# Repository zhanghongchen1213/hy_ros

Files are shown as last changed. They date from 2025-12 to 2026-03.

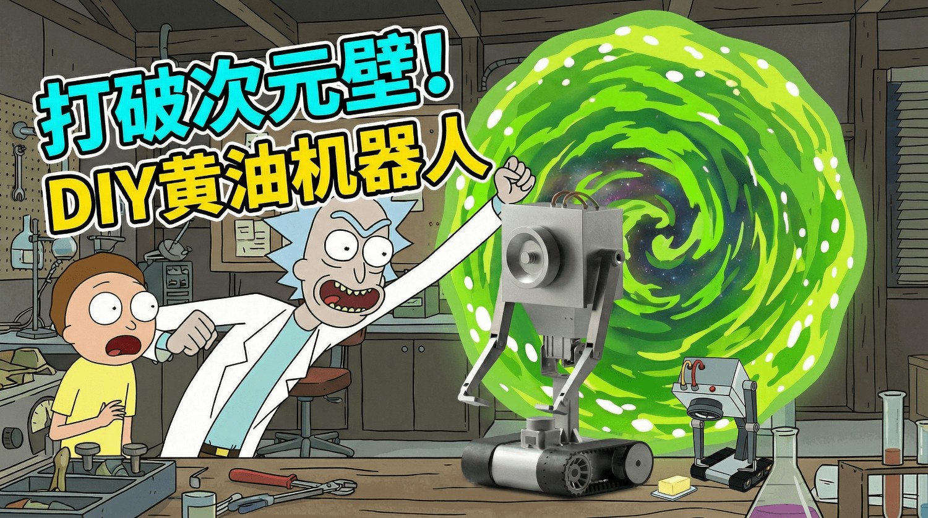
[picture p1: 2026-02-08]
Solidworks/视频封面A.png.yasuo.jpg

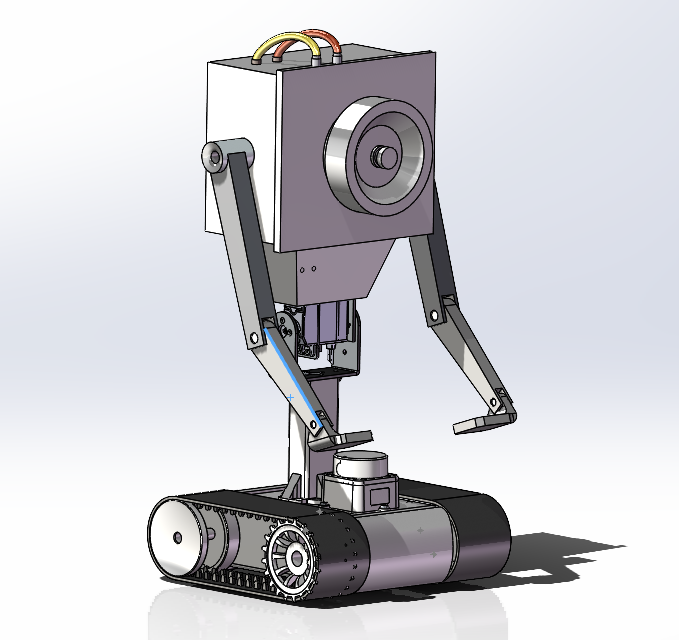
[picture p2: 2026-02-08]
Solidworks/���ͻ�����3D���ͼ/��Ļ��ͼ 2025-12-12 084811.png

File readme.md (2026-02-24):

# 全球首发！瑞克和莫蒂 专属定制黄油机器人！

## 🛒 购买链接

> 🐟 **闲鱼搜索**：`鸿尘客`
>
> 如有疑问可通过闲鱼私信联系卖家，支持定制化需求沟通。

# 📖 项目简介

**黄油机器人（Butter Robot）** 是一款基于 ROS2 Humble 的全功能自主移动机器人平台，采用 Rockchip RK3588S 作为主控芯片，搭配 ESP32S3 微控制器实现底层运动控制。项目涵盖感知、定位建图、运动控制、视觉处理和语音交互五大核心功能模块，是一个集成度较高的机器人学习与开发平台。

# 🔗 开源地址

| 平台 | 链接 |
| --- | --- |
| 个人博客 | [https://zhcmqtt.top](https://zhcmqtt.top) |
| CSDN博客 | [https://blog.csdn.net](https://blog.csdn.net/weixin_46477159?spm=1000.2115.3001.5343) |
| 立创硬件开源 | [https://x.jlc.com](https://oshwhub.com/nhwjxzxz/huang-you-ji-qi-ren) |
| GitHub——ROS算法开源 | [https://github.com/zhanghongchen1213/hy_ros](https://github.com/zhanghongchen1213/hy_ros) |
| GitHub——驱动器算法开源 | [https://github.com/zhanghongchen1213/hy_driver](https://github.com/zhanghongchen1213/hy_driver) |
| GitHub——yolo训练算法开源 | [https://github.com/zhanghongchen1213/butter_yolov8n_train](https://github.com/zhanghongchen1213/butter_yolov8n_train) |
| 开发教程开源 | [https://hy-ros.readthedocs.io](https://hy-ros.readthedocs.io/zh-cn/latest/1_product_introduction.html) |

# 📷 产品外观

| | |
| :---: | :---: |
| (https://imgloc.com/image/yl9J6U) | (https://imgloc.com/image/yl9EAF) |
| (https://imgloc.com/image/yl9BC0) | (https://imgloc.com/image/yl9lw9) |
| (https://imgloc.com/image/yl9KLc) | (https://imgloc.com/image/yl9YdX) |
| (https://imgloc.com/image/yl9GcO) | (https://imgloc.com/image/yl9m6d) |

# 🏗️ 系统架构

系统采用分层模块化架构，主要分为以下五层：

- **感知层**：集成 LDLiDAR 2D 激光雷达（360° 环境扫描）、1080P 摄像头、6 轴 IMU 惯性测量单元和轮式编码器里程计，提供多源环境感知能力。
- **定位与建图层**：基于 slam_toolbox 实现在线异步 SLAM 建图，通过 robot_localization 扩展卡尔曼滤波（EKF）融合轮式里程计与 IMU 数据，并使用 laser_filters 过滤机器人自身遮挡。
- **控制层**：通过 UART 串口（460800 波特率）与 ESP32S3 通信，实现差速驱动底盘的 PID 速度控制和舵机控制，支持键盘、手柄、语音等多种输入方式。
- **视觉处理层**：利用 RK3588S 的 NPU（6TOPS 算力）硬件加速 YOLOv8 目标检测，三个视觉组件（采集、推理、推流）运行在同一 ComposableNodeContainer 中，通过零拷贝通信降低延迟。
- **交互层**：集成 sherpa-onnx ASR 语音识别、RKLLM 本地大语言模型推理和百度大模型音色复刻 TTS 语音合成，实现全流式语音交互；同时通过 Foxglove Bridge 提供 Web 端远程监控与数字孪生可视化。

# 🎬 视频演示

点击观看视频 (https://www.bilibili.com/video/BV1hQcFzrEXS/?spm_id_from=333.1007.top_right_bar_window_history.content.click)

> 📺 **视频作者**：B站 @鸿尘客
> 🔗 **视频链接**：[黄油机器人](https://www.bilibili.com/video/BV1hQcFzrEXS/?spm_id_from=333.1007.top_right_bar_window_history.content.click)

# ⚙️ 硬件规格

| 项目 | 参数 |
| :---: | :---: |
|  主芯片 SOC  | Rockchip RK3588S |
| CPU | 4 核 Cortex-A76(2.4GHZ)+4 核 Cortex-A5(1.8GHZ) |
| NPU | 6TOPS |
| VPU | H.264/H.265/JPEG 硬件编解码 |
| RAM | LPDDR5 8GB |
| TF | 32GB |
|  Wi-Fi+蓝牙  | Wi-Fi 5+BT 5.0 |
|  驱动器 MCU  | ESP32S3 |
| 电池容量 | 3000mAh 12V |
| 摄像头分辨率 | 1920x1080 30FPS |
| 操作系统 | Ubuntu22.04 |
| ROS 版本 | ROS2 Humble |

# 📐 硬件框图

(https://imgloc.com/image/ylD0Gx)

# 🚀 产品功能

> **五大核心能力**：语音交互 | 运动控制 | 视觉处理 | 定位导航 | 远程监控

---

## 🗣️ 语音交互 —— 全链路语音对话，开口即控制

| 模块 | 核心能力 | 技术方案 |
| :---: | :--- | :--- |
|  **ASR 语音识别**  | 中英双语实时识别，增量输出无需等待整句 | sherpa-onnx + RKNN 加速 Zipformer，48kHz→16kHz 重采样，端点检测  |
| **LLM 大语言模型** | 本地多模态推理，语音触发拍照+图像理解 | Qwen3-VL-2B W8A8 量化，RK3588 NPU 加速，4096 上下文，流式输出 |
|  **TTS 语音合成**  | 自定义音色克隆，支持多种方言，边合成边播放 | 百度大模型音色复刻 API，句级分段合成，HTTP 流式推送（端口 8090） |

## 🎮 运动控制 —— 多模式操控，精准灵活

| 模块 | 核心能力 | 技术方案 |
| :---: | :--- | :--- |
| **差速驱动底盘** | PID 闭环控制，实时调参，最大线速度 0.15 m/s  | UART 460800 波特率通信 ESP32S3，自定义二进制协议，左右电机独立控制 |
| **舵机控制** | 3 路舵机控制脊柱和双臂关节，URDF 实时联动 | `/joint_states` 话题发布关节状态，角度精确控制 |
| **键盘遥控** | WASD 八方向移动，0.1 秒无操作自动停车 | 100Hz 轮询频率 |
| **手柄遥控** | 摇杆模拟量控制速度，按键控制舵机（±5° 步进） | 线速度 + 角速度双轴控制 |
| **语音遥控** | 通过语音交互链路下发运动指令 | ASR → LLM → 运动指令 |

## 👁️ 视觉处理 —— NPU 硬件加速，零拷贝低延迟

| 模块 | 核心能力 | 技术方案 |
| :---: | :--- | :--- |
| **摄像头采集** | 1080P@30fps 硬件加速采集，支持 RGA 硬件旋转 | GStreamer + v4l2src，NV12 原生格式输出 |
|  **目标检测**  | 黄油/手掌检测 + 自主跟随 | YOLOv8 + RKNN NPU 加速，640x640，NMS 0.45  |
|  **视频推流**  | RTSP 实时推流，零拷贝进程内通信 | MPP 硬件 H.264 编码，ComposableNode 零拷贝 |

## 🗺️ 定位导航 —— SLAM 建图 + Nav2 自主导航

| 模块 | 核心能力 | 技术方案 |
| :---: | :--- | :--- |
| **里程计融合** | 50Hz EKF 融合轮式里程计与 IMU，输出高精度位姿 | robot_localization，2D 模式，odom → base_link TF |
| **SLAM 建图**  | 在线异步建图，回环检测，0.05 m/pixel 分辨率 | slam_toolbox + Ceres 求解器，激光量程 12.0 m |
| **纯定位模式** | 加载已有地图重定位，过滤自身遮挡 | slam_toolbox 定位模式 + laser_filters |
|  **自主导航**  | 全局路径规划 + 局部避障 | Nav2 导航栈，DWA / TEB 规划算法 |

## 🖥️ 远程监控 —— Web 端数字孪生，随时随地掌控

| 能力 | 说明 |
| :---: | :--- |
| **Foxglove 可视化** | WebSocket（端口 8765）实时查看机器人状态、话题数据和 TF 坐标树 |
| **RTSP 视频流** | 远程查看摄像头画面及目标检测结果 |
| **远程控制** | Web 端发布控制指令，实现数字孪生效果 |

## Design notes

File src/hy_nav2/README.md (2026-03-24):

# hy_nav2 功能包

Nav2 自主导航与任务调度功能包，实现"搜索黄油 → 导航抓取 → 返回起点"的自主任务。

## 功能说明

- **任务调度节点** (`butter_mission_node`): 状态机管理，协调导航和抓取任务
- **Nav2 导航栈**: AMCL定位 + 全局规划 + 局部避障
- **配置文件**: 适配黄油机器人的 Nav2 参数

## 编译

```bash
cd ~/hy_linux/nfs/hy_ros
colcon build --packages-select hy_nav2
source install/setup.bash
```

## 运行

### 1. 启动基础系统
```bash
ros2 launch ldlidar_driver_ros2 ldlidar_driver.launch.py &
ros2 launch uart uart_launch.py &
ros2 launch ekf_odom ekf_odom_launch.py &
ros2 launch hy_slam laser_filter_only.launch.py
```

### 2. 启动视觉检测
```bash
ros2 launch rk_camera camera_inference_streamer.launch.py
```

### 3. 启动 Nav2 导航栈
```bash
ros2 launch hy_nav2 nav2_bringup.launch.py
```

### 4. 启动任务调度
```bash
ros2 launch hy_nav2 butter_mission.launch.py
```

## 参数配置

在 `butter_mission.launch.py` 中可配置：
- `center_x`: 搜索中心点 X 坐标
- `center_y`: 搜索中心点 Y 坐标
- `search_angular_speed`: 搜索旋转速度

## 依赖

- ROS2 Humble
- navigation2
- nav2_bringup
- slam_toolbox
- hy_slam (地图文件)

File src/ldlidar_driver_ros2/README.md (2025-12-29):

①编译方法：使用catkin编译，执行如下操作
将功能包解压后复制到工作空间的路径下，然后执行指令“catkin_make”进行编译。
单独编译功能包：
colcon build --packages-select ldlidar_driver_ros2

②设备别名：端口设备重命名
launch中启动的LD06/STL-19P/LD19雷达默认设备名为：/dev/ldlidar_serial，别名文件是“ldlidar_udev.sh”，
如果您使用的ttl电平转换芯片为CP2102，设备号需要改为0001；

具体修改方法请分别查看对应的驱动资料。

③运行方法
启动：STL-19P雷达
source install/setup.bash
ros2 launch ldlidar_driver_ros2 ldlidar_driver.launch.py

④rviz可视化查看点云：
开启rviz2，rviz的基坐标选择laser，选择“laserscan”的可视化类型，话题选择“scan”。

⑤雷达角度分割
启用雷达角度分割：{'enable_angle_crop_func': True}
禁用雷达角度分割：{'enable_angle_crop_func': False}

## 测试：代码在ubuntun20.04 humble版本下测试，使用rviz2可视化。

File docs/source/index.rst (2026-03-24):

黄油机器人
===============================================================================================================

.. toctree::
   :maxdepth: 1
   :caption: 产品简介
   
   1_product_introduction
   
.. toctree::
   :maxdepth: 1
   :caption: 开发教程
   
   3_Development_instructions

.. toctree::
   :maxdepth: 1
   :caption: 参考链接
   
   6_Reference_links

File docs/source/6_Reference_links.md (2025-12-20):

# 参考资料

整理了本项目开发过程中参考的重要文档、开源项目及工具链接，供后续开发与维护查阅。

- **ROS 2 Documentation (Humble)**
  - 官方权威文档，包含安装、教程、API 说明。
  - 链接：<https://docs.ros.org/en/humble/>
- **ROS 2 Design**

  - ROS 2 的设计理念与架构说明（REP）。
  - 链接：<https://design.ros2.org/>

- **Ultralytics YOLOv8**
  - 实时目标检测、分割、姿态估计框架。
  - 链接：<https://docs.ultralytics.com/>
- **RKNN-Toolkit2**
  - 瑞芯微 NPU 模型转换与推理工具链。
  - 链接：<https://github.com/airockchip/rknn-toolkit2>
- **OpenCV**

  - 开源计算机视觉库文档。
  - 链接：<https://docs.opencv.org/4.x/>

- **Docker Documentation**
  - 容器化部署官方指南。
  - 链接：<https://docs.docker.com/>
- **NVIDIA Container Toolkit**

  - Docker 调用 GPU 配置指南。
  - 链接：<https://docs.nvidia.com/datacenter/cloud-native/container-toolkit/latest/index.html>

- **Colcon**
  - ROS 2 构建工具使用手册。
  - 链接：<https://colcon.readthedocs.io/>
- **Foxglove Studio**

  - 可视化调试工具文档。
  - 链接：<https://foxglove.dev/docs>

- **参考资源**

  - [小白机器人](https://newbot.readthedocs.io/zh-cn/latest/1_product_introduction.html)
  - [Github 鱼香 ros](https://github.com/fishros)
  - [SolidWorks 模型转 urdf](https://zhuanlan.zhihu.com/p/702891935)
  - [URDF 在线显示网站](https://gkjohnson.github.io/urdf-loaders/javascript/example/bundle/)
  - [sherpa-onnx-python—api](https://github.com/k2-fsa/sherpa-onnx/blob/master/python-api-examples/speech-recognition-from-microphone-with-endpoint-detection.py)
  - [rk3588-sherpa-onnx 语音识别](https://blog.csdn.net/chui_yu666/article/details/147338735)
  - [香橙派 RK3588 部署千问大模型 Qwen2-VL-2B ](https://blog.csdn.net/lajuchenghui/article/details/150111489)
  - [RKLLM Qwen2-VL](https://docs.radxa.com/rock5/rock5t/app-development/rkllm_qwen2_vl)
  - [RKLLM 部署](https://doc.embedfire.com/linux/rk356x/Ai/zh/latest/lubancat_ai/env/rkllm.html)
  - [百度大模型声音复刻](https://cloud.baidu.com/doc/SPEECH/s/Am8wytft2)
  - [RKLLM 文档](https://github.com/airockchip/rknn-llm/blob/main/doc/Rockchip_RKLLM_SDK_CN_1.2.3.pdf)
  - [RKNNLLM c++ api](https://github.com/airockchip/rknn-llm/blob/main/examples/rkllm_api_demo/deploy/src/llm_demo.cpp)
  - [Gstreamer 工具以及 MPP 插件](https://doc.embedfire.com/linux/rk356x/quick_start/zh/latest/lubancat_rk_software_hardware/software/gstreamer/gstreamer.html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)

- 根据端侧的终端报错信息，首先我需要你以文字形式描述终端遇到的报错具体是什么信息。然后提供解决方案，但是不需要你在终端运行，运行我的代码是运行在端侧的。你只需要提供我如何在终端运行什么命令就可以了。

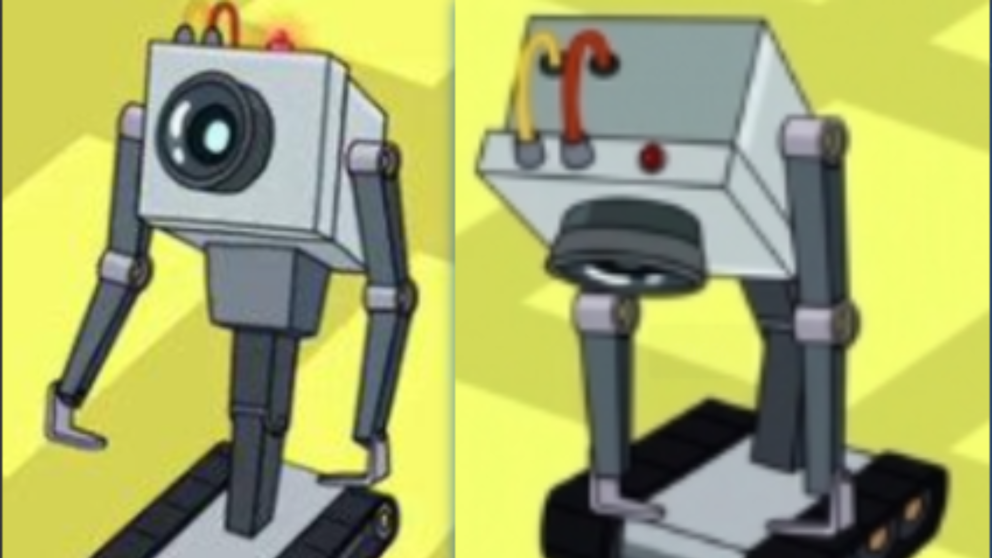
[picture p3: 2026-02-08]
Solidworks/���ͻ�����3D���ͼ/IMG_202512129949_1920x1080.png

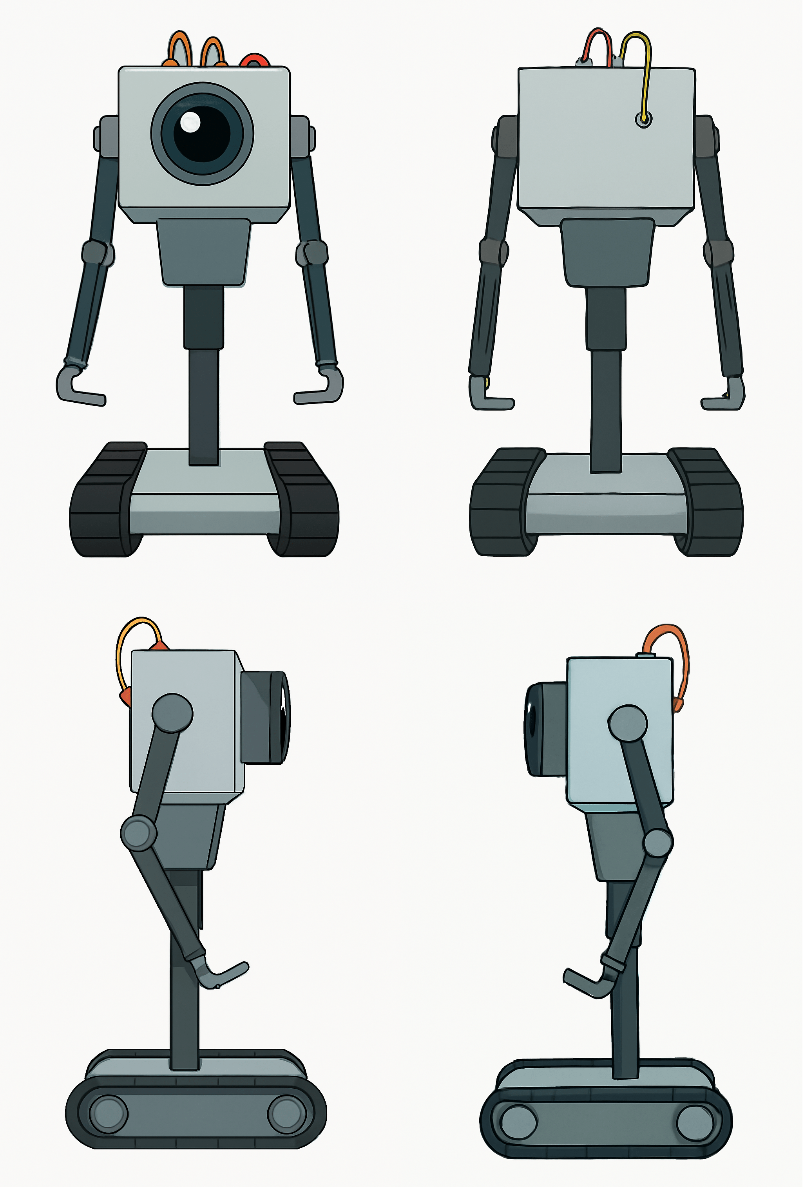
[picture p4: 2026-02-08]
Solidworks/���ͻ�����3D���ͼ/���ͻ��������ͼ@���ƿ�ͼ.png

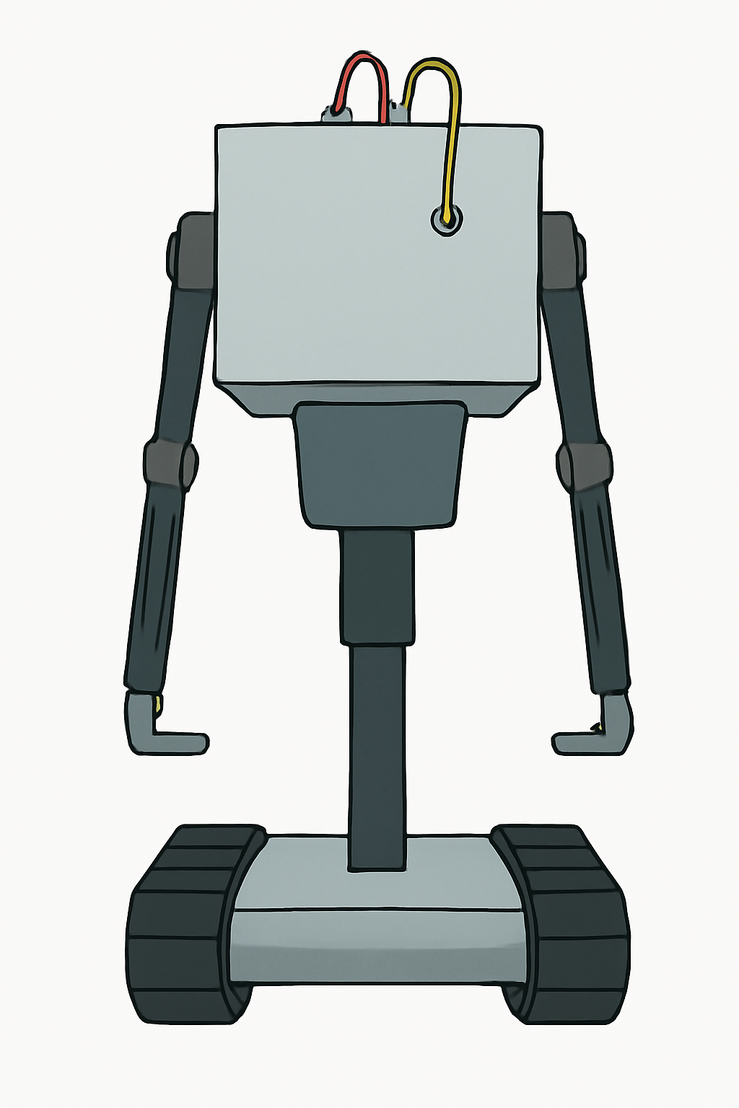
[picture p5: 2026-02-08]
Solidworks/���ͻ�����3D���ͼ/���ͻ����˺���ͼ.png

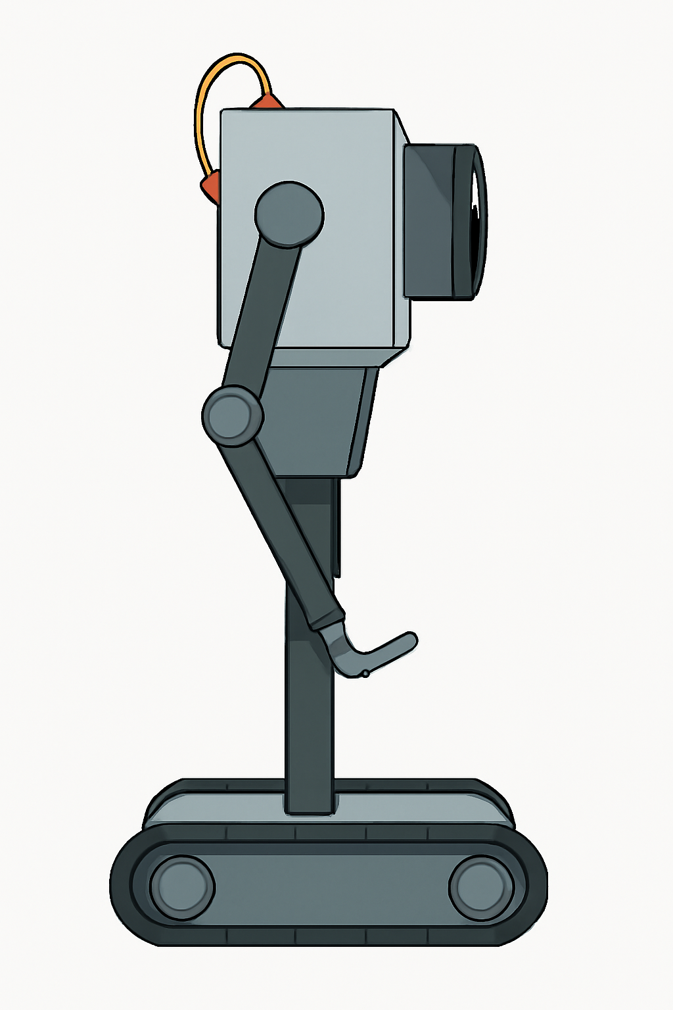
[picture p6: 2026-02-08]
Solidworks/���ͻ�����3D���ͼ/���ͻ���������ͼ.png

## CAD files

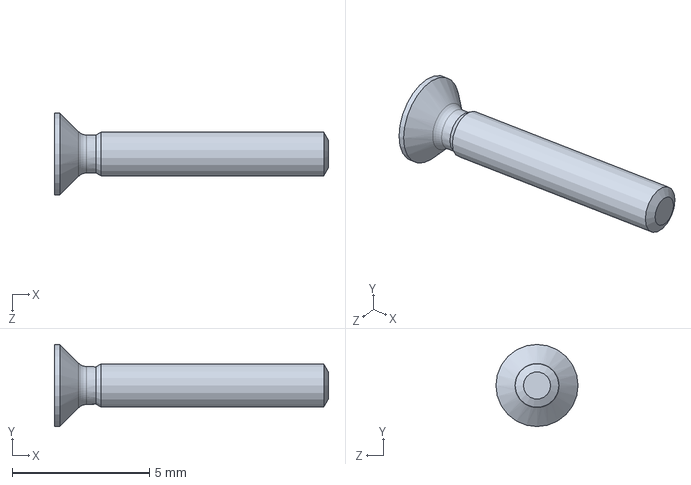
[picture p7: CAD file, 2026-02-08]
Solidworks/�ͻ�/GB�T819�1-2000ʮ�ֲ۳�ͷ�ݶ�M1�6�10.SLDPRT
10.0 x 3.00 x 3.00 mm

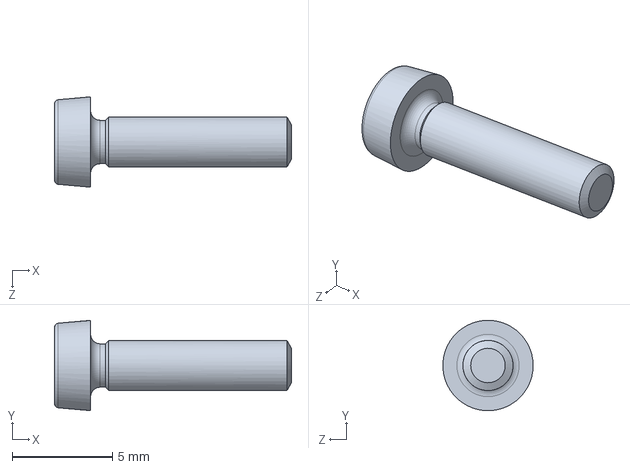
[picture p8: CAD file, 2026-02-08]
Solidworks/�ͻ�/�׼�/GB�T822-2000ʮ�ֲ�Բ�ͷ�ݶ�M2�5�10.SLDPRT
11.8 x 4.50 x 4.50 mm

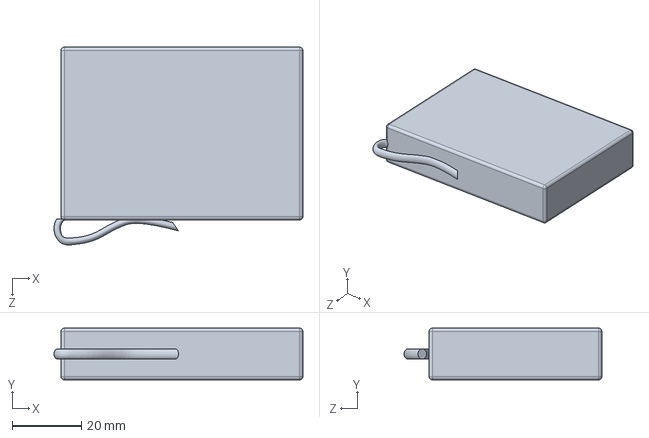
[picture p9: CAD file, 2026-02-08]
Solidworks/�ͻ�/�⹺�/3000mAh�.SLDPRT
72.0 x 15.0 x 57.2 mm

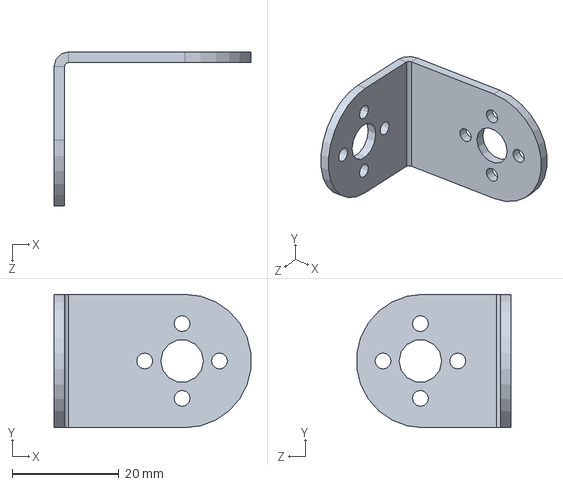
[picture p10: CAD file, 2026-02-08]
Solidworks/�ͻ�/�⹺�/�֧�/001 �֧�ͼֽ/000 PRT/L�֧�.SLDPRT
36.9 x 25.0 x 28.9 mm

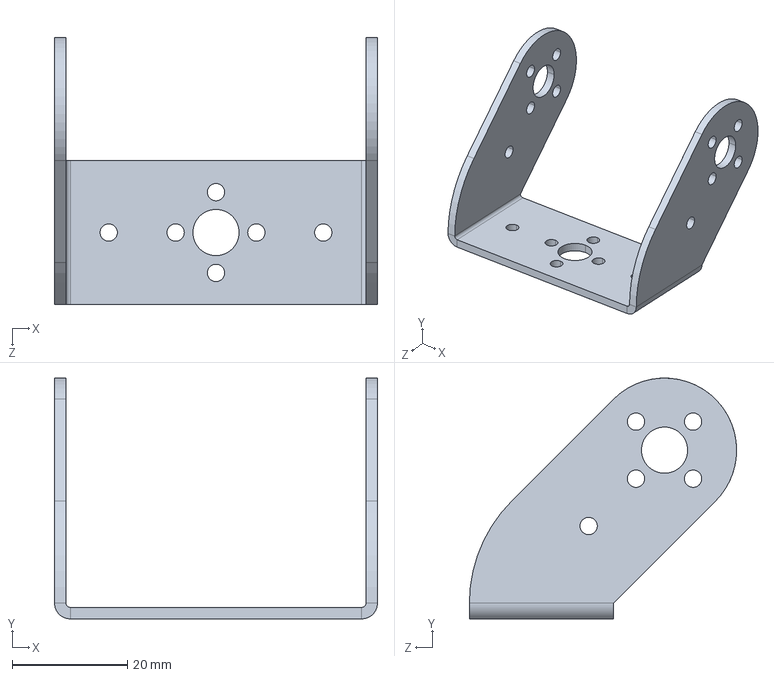
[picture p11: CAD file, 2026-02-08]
Solidworks/�ͻ�/�⹺�/�֧�/001 �֧�ͼֽ/001 STP/бU.STEP
56.0 x 41.7 x 46.3 mm

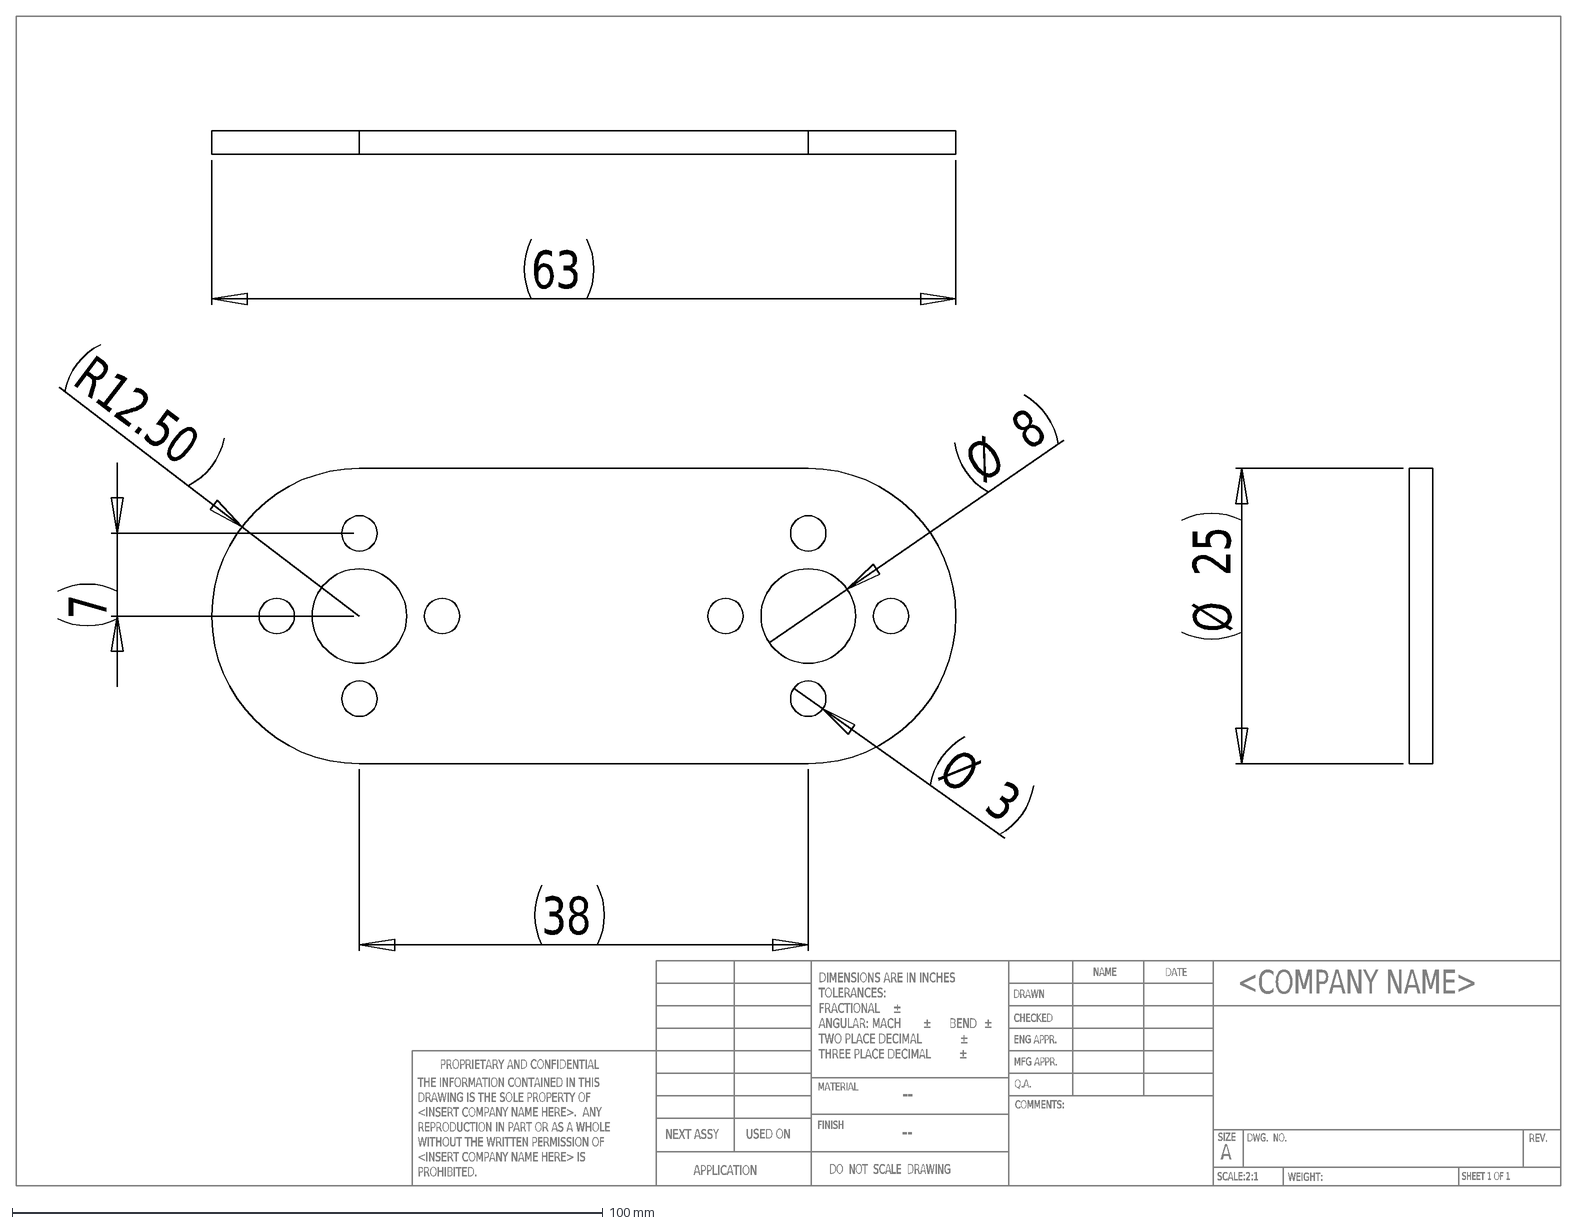
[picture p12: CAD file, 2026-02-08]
Solidworks/�ͻ�/�⹺�/�֧�/001 �֧�ͼֽ/002 CAD/һ�֧�.DXF
<COMPANY NAME>
SCALE:2:1
SIZE
DWG. NO.
A
REV.
MATERIAL
FINISH
--
DO NOT SCALE DRAWING
APPLICATION
USED ON
NEXT ASSY
DIMENSIONS ARE IN INCHES
TOLERANCES:
FRACTIONAL
±
ANGULAR: MACH
BEND
TWO PLACE DECIMAL
THREE PLACE DECIMAL
NAME
DATE
DRAWN
CHECKED
ENG APPR.
MFG APPR.
Q.A.
SHEET 1 OF 1
WEIGHT:
COMMENTS:
THE INFORMATION CONTAINED IN THIS
DRAWING IS THE SOLE PROPERTY OF
<INSERT COMPANY NAME HERE>. ANY
REPRODUCTION IN PART OR AS A WHOLE
WITHOUT THE WRITTEN PERMISSION OF
<INSERT COMPANY NAME HERE> IS
PROHIBITED.
PROPRIETARY AND CONFIDENTIAL
38
R12.50
Ø
3
7
8
63
25

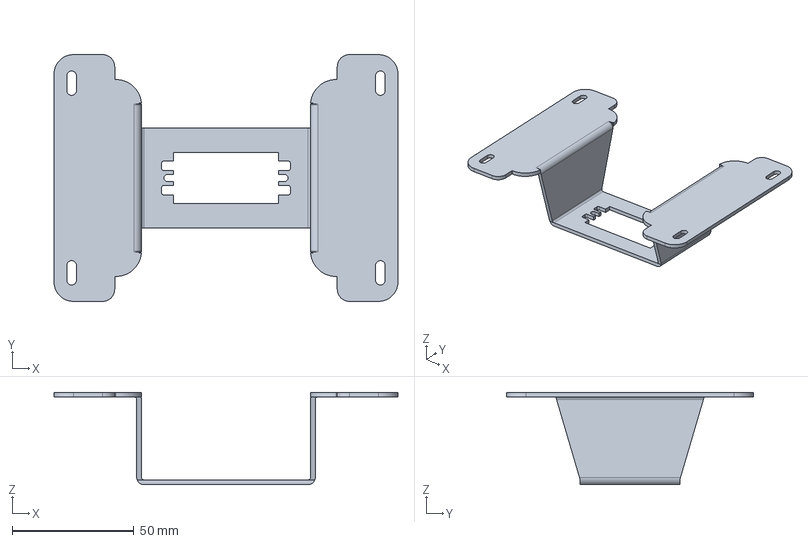
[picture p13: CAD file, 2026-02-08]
Solidworks/�ͻ�/�⹺�/�֧�/U�ʹ�װ�.stp
141.5 x 101.5 x 38.0 mm

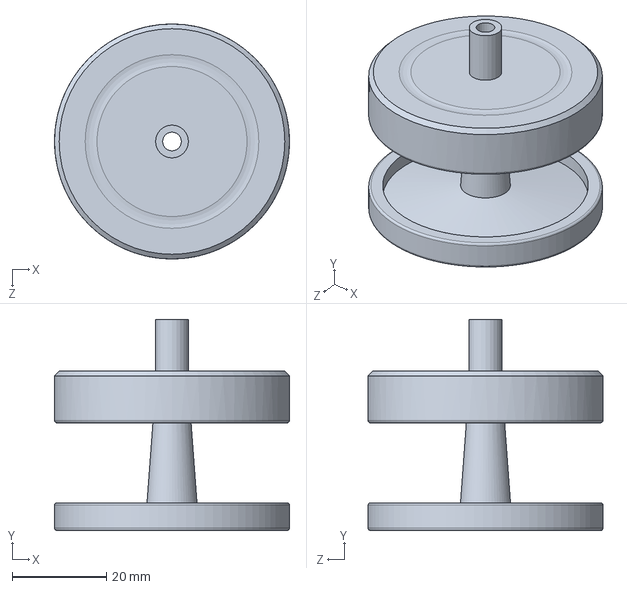
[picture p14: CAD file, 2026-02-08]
Solidworks/���ͻ�����/�⹺��/�Ӷ���.SLDPRT
50.0 x 44.9 x 50.0 mm

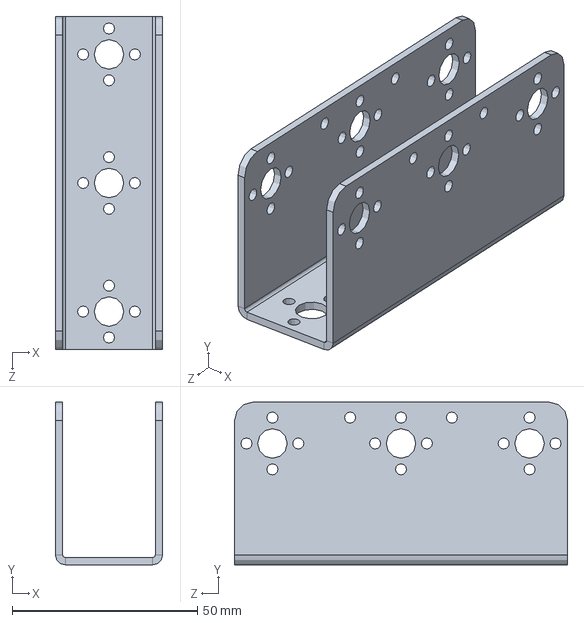
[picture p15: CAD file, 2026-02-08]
Solidworks/���ͻ�����/�⹺��/����֧��/001 ����֧��ͼֽ/000 PRT/U����֧��.SLDPRT
29.0 x 44.0 x 90.0 mm

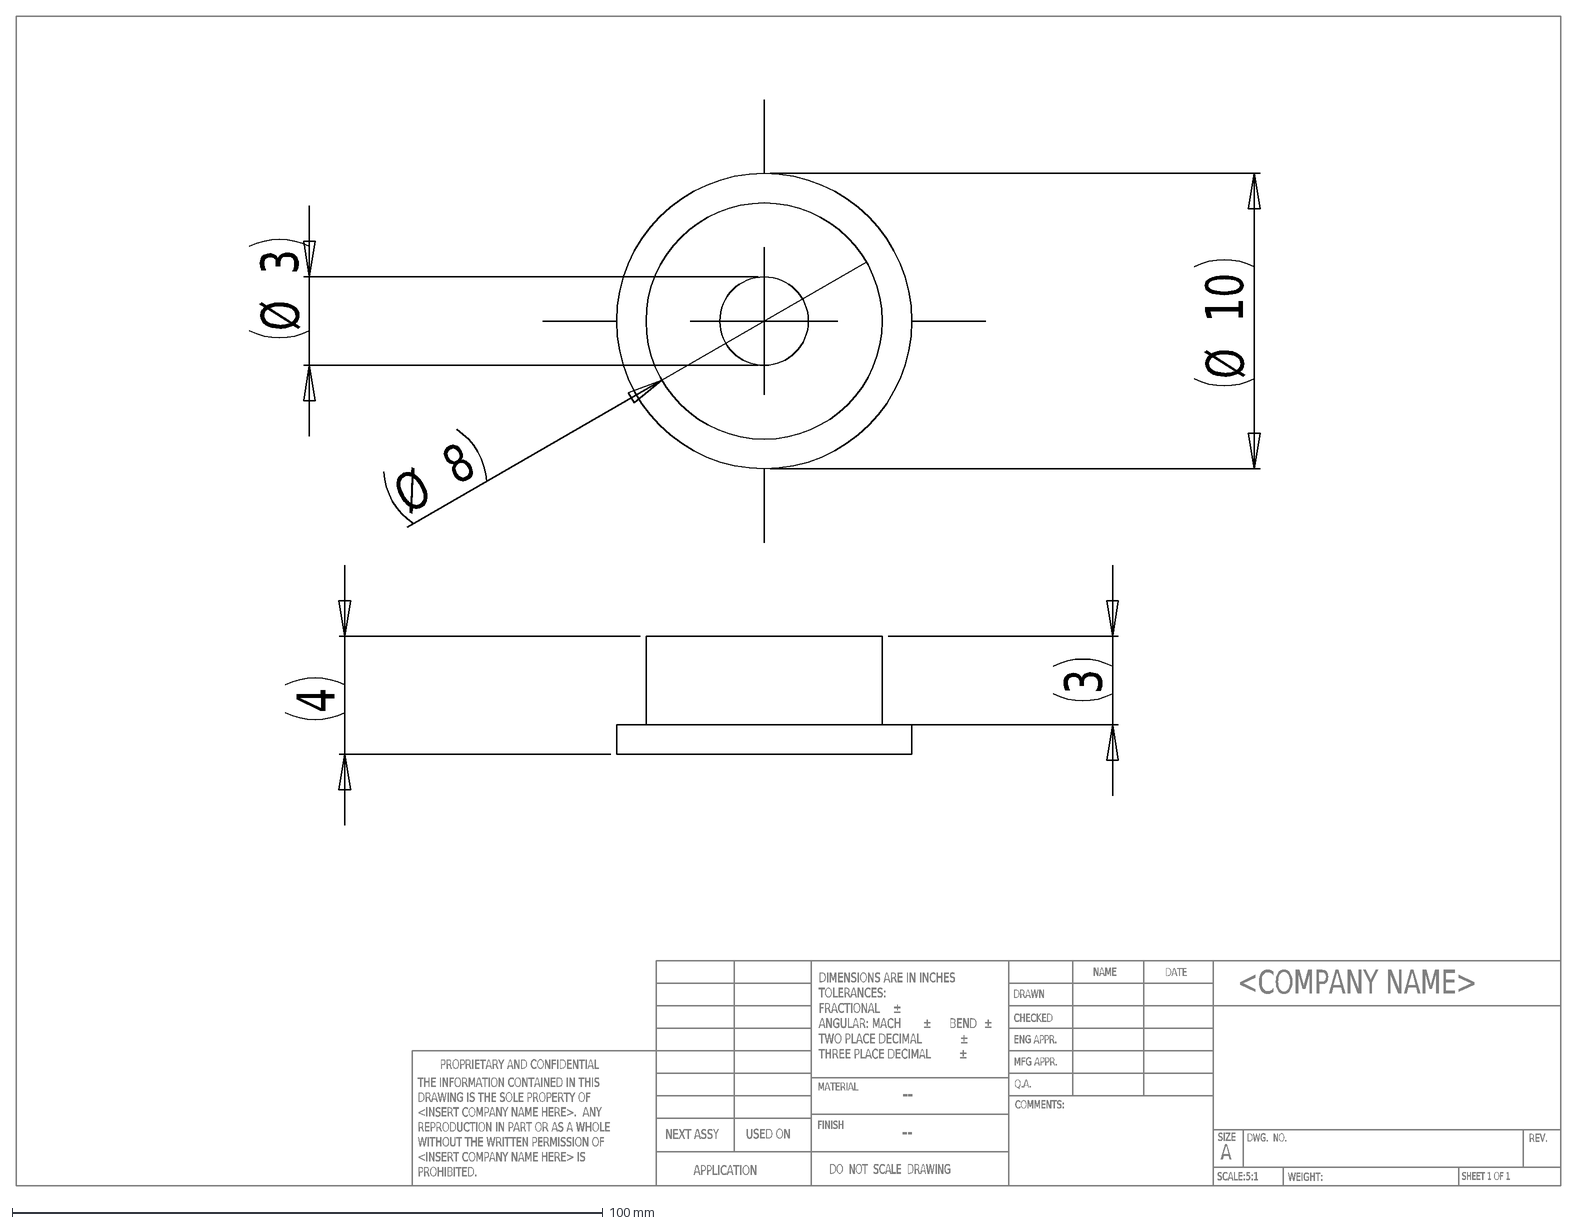
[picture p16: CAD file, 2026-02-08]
Solidworks/���ͻ�����/�⹺��/����֧��/001 ����֧��ͼֽ/002 CAD/��ʽ���.DXF
<COMPANY NAME>
SCALE:5:1
SIZE
DWG. NO.
A
REV.
MATERIAL
FINISH
--
DO NOT SCALE DRAWING
APPLICATION
USED ON
NEXT ASSY
DIMENSIONS ARE IN INCHES
TOLERANCES:
FRACTIONAL
±
ANGULAR: MACH
BEND
TWO PLACE DECIMAL
THREE PLACE DECIMAL
NAME
DATE
DRAWN
CHECKED
ENG APPR.
MFG APPR.
Q.A.
SHEET 1 OF 1
WEIGHT:
COMMENTS:
THE INFORMATION CONTAINED IN THIS
DRAWING IS THE SOLE PROPERTY OF
<INSERT COMPANY NAME HERE>. ANY
REPRODUCTION IN PART OR AS A WHOLE
WITHOUT THE WRITTEN PERMISSION OF
<INSERT COMPANY NAME HERE> IS
PROHIBITED.
PROPRIETARY AND CONFIDENTIAL
4
3
Ø
10
8

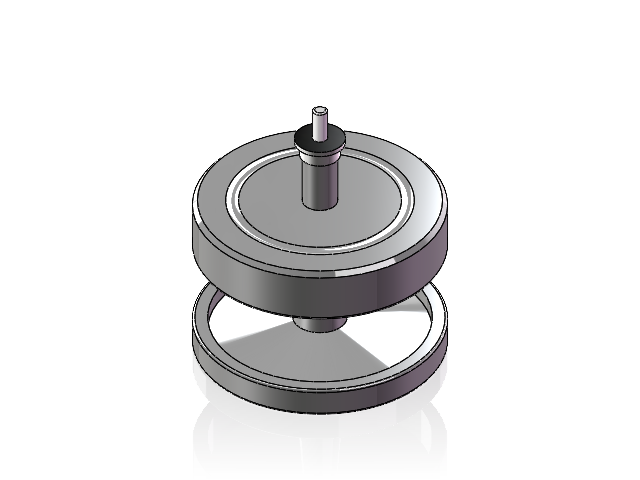
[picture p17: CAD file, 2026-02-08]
Solidworks/���ͻ�����/�Ӷ���װ��.SLDASM
从动轮
杯士轴承384
GB／T819．1-2000十字槽沉头螺钉M3×40

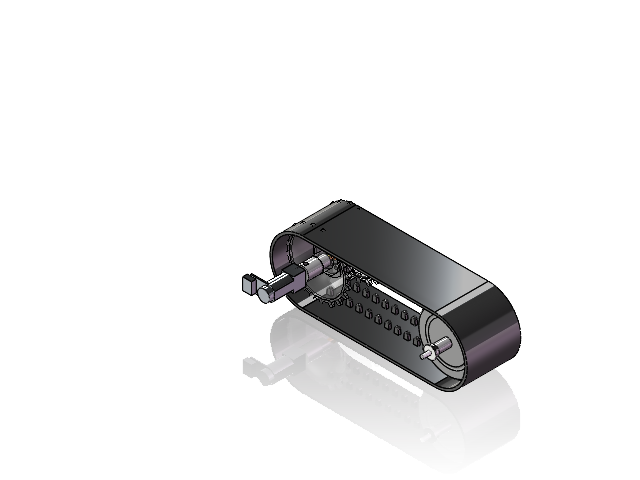
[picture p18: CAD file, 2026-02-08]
Solidworks/�ͻ�/�Ĵ�װ�.SLDASM
驱动轮
N20减速电机
GB818-M3X10-ZN-4.8
联轴器CNC
从动轮
杯士轴承384
GB／T819．1-2000十字槽沉头螺钉M3×40
小履带

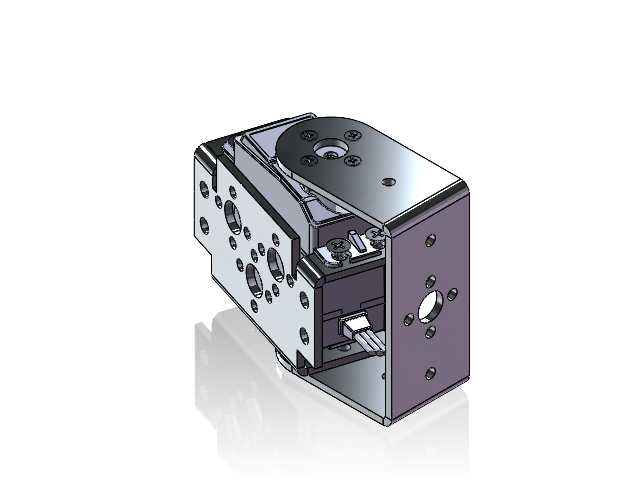
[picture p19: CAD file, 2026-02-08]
Solidworks/���ͻ�����/���װ��.SLDASM
单轴舵机PM20S
多功能支架
短U支架
杯士轴承384
GB／T819．1-2000十字槽沉头螺钉M2×8 x 4
GB／T819．1-2000十字槽沉头螺钉M3×8 x 5
GB／T6170-20001型六角螺母A级和B级M3 x 5

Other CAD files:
Solidworks/���ͻ�����/�⹺��/����֧��/001 ����֧��ͼֽ/001 STP/L��֧��.STEP
Solidworks/�ͻ�/3D_�ת�Ӱ�_2025-11-29.SLDPRT
Solidworks/�ͻ�/GB�T819�1-2000ʮ�ֲ۳�ͷ�ݶ�M1�6�6.SLDPRT
Solidworks/�ͻ�/GB�T822-2000ʮ�ֲ�Բ�ͷ�ݶ�M2�5.SLDPRT
Solidworks/�ͻ�/GB�T822-2000ʮ�ֲ�Բ�ͷ�ݶ�M2�5�8.SLDPRT
Solidworks/�ͻ�/XLDC-01.SLDPRT
Solidworks/�ͻ�/XLDC-02.SLDPRT
Solidworks/�ͻ�/ת�.SLDPRT
Solidworks/�ͻ�/�.SLDPRT
Solidworks/�ͻ�/�.sldprt
Solidworks/�ͻ�/�.step
Solidworks/�ͻ�/�CNC.SLDPRT
Solidworks/�ͻ�/�CNC.STEP
Solidworks/�ͻ�/�CNC.slddrw
Solidworks/�ͻ�/�ɹ̶�.SLDPRT
Solidworks/�ͻ�/�ʾ�.SLDPRT
Solidworks/�ͻ�/�̶̹�.SLDPRT
Solidworks/�ͻ�/�̶̹�.STEP
Solidworks/�ͻ�/�Դ�.SLDPRT
Solidworks/�ͻ�/�̶ֹ�.SLDPRT
Solidworks/�ͻ�/�װ�.SLDPRT
Solidworks/�ͻ�/�׼�/GB6170-M4-ZN-10.SLDPRT
Solidworks/�ͻ�/�׼�/GB818-M3X10-ZN-4.8.SLDPRT
Solidworks/�ͻ�/�׼�/GB818-M4XX-4.8.SLDPRT
Solidworks/�ͻ�/�׼�/GB�T117-2000Բ׶�A�4�10.SLDPRT
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

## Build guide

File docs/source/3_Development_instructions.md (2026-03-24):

# 一、主机环境配置

本项目主机环境为 Ubuntu22.04 系统，确保与端侧处于同一局域网络环境。

1. 启动本项目文件中配置 NFS 服务器脚本，挂载本地 NFS 目录: `sudo nfs_config.sh`

2. 将本项目文件放到 `/home/${SUDO_USER:-$USER}/hy_linux/nfs` 目录下

3. 参考教程：[鱼香 ROS2 一键安装](https://blog.csdn.net/weixin_71683006/article/details/150465016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)

   ```shell
   # 一键配置ROS2 humble开发环境
   cd /opt
   wget --no-check-certificate https://fishros.com/install -O fishros
   chmod +x fishros
   ./fishros
   # 1:一键安装 -> 1:更换系统源再继续安装 -> 2:更新系统源并清理第三方源 -> 1：自动测速选择最快的源 -> \
   # 1:中科大镜像源 -> 1:humble(ROS2) -> 1:humble(ROS2)桌面版 -> 开始自动安装等待20min左右
   ```

   (https://imgloc.com/image/ylDjRa)

4. 可在主机环境按照相同方法同步配置完 ros2 后，测试双端通信是否成功

   - 端侧：`ros2 run demo_nodes_cpp talker`
   - 主机侧：`ros2 run demo_nodes_cpp listener`

   (https://imgloc.com/image/ylDFP4)

5. 安装必要的 python 库

   ```shell
   # 用于语音复刻模型
   sudo apt-get install python3-aiohttp python3-websockets
   ```

# 二、端侧环境配置

## 1. 个人初始配置

### 1.1 烧录镜像文件

烧录镜像文件 **Orangepi5pro_1.0.6_ubuntu_jammy_server_linux5.10.160** 到 tf 卡中。

### 1.2 修改 root 用户自动登录终端

密码为 **orangepi**

```shell
sudo auto_login_cli.sh root
```

### 1.3 连接 wifi

```{note}
输入自己的 wifi 名和密码，并记录 ip 地址。
```

```shell
sudo nmcli dev wifi connect wifi名称 password wifi密码
ip addr show wlan0
```

### 1.4 SSH 远程连接测试

密码为 orangepi

```{note}
替换为端侧 ip 地址。例如 192.168.22.188
```

```shell
ssh root@端侧IP地址
```

## 2. 挂载配置

### 2.1 挂载 NFS

```{important}
挂载命令中需修改为实际的 ubuntu 主机侧 IP 地址（如 192.168.22.177）、NFS 开发路径（如 /home/k/hy_linux/nfs）和端侧挂载路径（如 /mnt/nfs）。
```

```shell
# 1. 安装和挂载NFS
sudo apt update
sudo apt install -y nfs-common
mkdir /mnt/nfs
# 手动挂载，重启后不会自动挂载
sudo mount -t nfs -o nolock 主机IP地址:/主机挂载路径 端侧挂载路径
sudo mount -t nfs -o nolock 192.168.22.177:/home/k/hy_linux/nfs /mnt/nfs

# 2. 配置nfs开机自动挂载
# 2.1 修改环境变量，设置开机自动加载~/.bashrc
echo -e 'if [ -f ~/.bashrc ]; then\n    . ~/.bashrc\nfi' >> ~/.bash_profile

# 2.2 修改环境变量，添加自动挂载nfs命令并激活环境
echo 'sudo mount -t nfs -o nolock 192.168.22.177:/home/k/hy_linux/nfs /mnt/nfs' >> ~/.bashrc
source ~/.bash_profile
```

### 2.2 挂载 emmc(可选)

```shell
# 挂载emmc作为存储空间并配置开机自动挂载
# 查看所有存储设备和分区，查看是否有未挂载的eMMC分区
lsblk
# 格式化存储空间大的分区格式化为ext4（-F强制格式化，-L添加卷标hy_tmp，方便识别）(按实际情况修改mmcblk0p2)
sudo mkfs.ext4 -F -L hy_tmp /dev/mmcblk0p2
# 创建挂载点目录
sudo mkdir -p /hy_tmp
# 设置目录权限（允许所有用户读写执行，方便存放文件）
sudo chmod 777 /hy_tmp
# 设置目录所有者（可选，让当前用户拥有完整权限）
sudo chown $USER:$USER /hy_tmp
# 查看mmcblk0p2的UUID（复制输出中的UUID值，不含引号）
blkid /dev/mmcblk0p2
# 使用nano编辑器打开fstab（新手推荐nano，操作简单）
sudo nano /etc/fstab
# 添加以下内容到fstab文件末尾(将UUID替换为实际值)
UUID=实际UUID /hy_tmp ext4 defaults 0 2
# 查看是否挂载成功
df -h
# 读写测试
# 进入/hy_tmp目录
cd /hy_tmp
# 创建测试文件夹和文件
mkdir video audio screenshot
touch audio/test.mp3 video/test.mp4 screenshot/test.png
# 查看创建结果
ls -l
```

## 3. 安装 ROS2 humble

参考教程：[鱼香 ROS2 一键安装](https://blog.csdn.net/weixin_71683006/article/details/150465016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)

```shell
# 一键配置ROS2 humble开发环境
cd /opt
wget --no-check-certificate https://fishros.com/install -O fishros
chmod +x fishros
./fishros
# 1:一键安装 -> 1:更换系统源再继续安装 -> 2:更新系统源并清理第三方源 -> 1：自动测速选择最快的源 -> \
# 1:中科大镜像源 -> 1:humble(ROS2) -> 1:humble(ROS2)桌面版 -> 开始自动安装等待20min左右
```

(https://imgloc.com/image/ylDjRa)

- 可在主机环境按照相同方法同步配置完 ros2 后，测试双端通信是否成功
  - 端侧：`ros2 run demo_nodes_cpp talker`
  - 主机侧：`ros2 run demo_nodes_cpp listener`

(https://imgloc.com/image/ylDFP4)

## 4. 硬件测试

### 4.1 摄像头测试

```shell
# 配置推流环境
mkdir /opt/camera
cd /opt/camera
# 安装cmake和libjpeg8-dev（用于编译mjpg-streamer）
sudo apt-get install cmake libjpeg8-dev
# 复制mjpg-streamer工具包到/opt/camera/目录下
cp /mnt/nfs/hy_ros/source/2.Camera/master.zip /opt/camera/
# 解压工具包
unzip master.zip
rm master.zip
cd mjp*g-*
make
sudo make install
# 安装v4l工具（用于查询摄像头参数）
sudo apt install -y v4l-utils
# 查看摄像头支持的格式、分辨率、帧率
v4l2-ctl --list-formats-ext
# 启动推流服务
/usr/local/bin/mjpg_streamer -i "/usr/local/lib/mjpg-streamer/input_uvc.so -d /dev/video0 -n -f 10 -r 1920x1080" -o "/usr/local/lib/mjpg-streamer/output_http.so -p 8085 -w /usr/local/share/mjpg-streamer/www"
```

```{tip}
打开浏览器，输入**端侧 IP 地址加端口号**（如：http://192.168.22.188:8085）即可查看实时视频流。
```

(https://imgloc.com/image/ylDTcN)

### 4.2 雷达测试

```shell
# 新建应用程序空间
mkdir /opt/lidar
cd /opt/lidar
# 上传wheeltec_udev.sh脚本到该目录，上传ldlidar_driver_python3.py文件到该目录
cp /mnt/nfs/hy_ros/source/1.Lidar/wheeltec_udev.sh /opt/lidar/
cp /mnt/nfs/hy_ros/source/1.Lidar/ldlidar_driver_python3.py /opt/lidar/
# 赋予执行权限
sudo chmod 777 wheeltec_udev.sh
sudo chmod 777 ld*
# 执行脚本
sudo ./wheeltec_udev.sh
# 重新插拔后检查更名是否成功（wheeltec_lidar -> ttyUSB0）
ll /dev
# 检查python版本，安装pyserial库
sudo apt install -y python3-pip
sudo pip3 install pyserial
# 执行对应测试脚本（输出刷新说明雷达正常工作）
python3 ldlidar_driver_python3.py
```

(https://imgloc.com/image/ylDU8H)

(https://imgloc.com/image/ylDARQ)

### 4.3 麦克风测试

```shell
# 查看麦克风设备列表
arecord -l
# 测试麦克风录音
mkdir -p /tmp/record
arecord --device=plughw:3,0 --format S16_LE --rate 44100 -c 2 -d 5 /tmp/record/test.wav
# 参数说明：
# --device=plughw:3,0：指定使用的麦克风设备（根据arecord -l输出的设备列表修改）
# --format S16_LE：指定音频格式为16位小端字节序
# --rate 44100：指定采样率为44100Hz
# -c 2：指定通道数为2（立体声）
# -d 5：指定录音时长为5秒
# /tmp/record/test.wav：指定输出文件路径
# 检查并下载test.wav文件是否录音成功
```

### 4.4 串口启动

```shell
# 启动串口3
sudo orangepi-config
# 依次选择System->Hardware -> uart3-m2 -> Space开启 -> save -> back -> Reboot
```

# 三、语音模型部署

## 1. 部署 Sherpa-ONNX-RKNPU 流式 ASR 模型

**参考：**[Sherpa-ONNX for RKNPU](https://k2-fsa.github.io/sherpa/onnx/rknn/install.html#)

### 安装 Sherpa-ONNX-RKNPU

```shell
# 1. ROS2功能包API调用库
sudo apt-get install libportaudio2  # 安装 PortAudio 库
pip3 install sounddevice # 安装 Python 音频处理库

# 2.安装sherpa-onnx，
mkdir /opt/sherpa-onnx
cd /opt/sherpa-onnx

# 1> 方式1：在线下载安装
pip install sherpa-onnx -f https://k2-fsa.github.io/sherpa/onnx/rk-npu-cn.html

# 2> 方式2：直接复制文件到/opt/sherpa-onnx/目录下
cp /mnt/nfs/hy_ros/source/0.RK3588S/1.sherpa-onnx/sherpa-onnx-cp310/sherpa_onnx-1.12.19-cp310-cp310-manylinux_2_27_aarch64.whl /opt/sherpa-onnx/
chmod +x /opt/sherpa-onnx/sherpa_onnx-1.12.19-cp310-cp310-manylinux_2_27_aarch64.whl
# 安装sherpa-onnx
pip3 install sherpa_onnx-1.12.19-cp310-cp310-manylinux_2_27_aarch64.whl
which sherpa-onnx

# 3.复制librknnrt.so文件到/opt/sherpa-onnx/目录下
cp /mnt/nfs/hy_ros/source/0.RK3588S/1.sherpa-onnx/sherpa-onnx-rknn-stream/librknnrt.so /opt/sherpa-onnx/
chmod +x /opt/sherpa-onnx/librknnrt.so

# 更新/lib/librknnrt.so 或 /usr/lib/librknnrt.so
cp /opt/sherpa-onnx/librknnrt.so /lib/
cp /opt/sherpa-onnx/librknnrt.so /usr/lib/

# 4. 系统级修复libonnxruntime.so库动态链接问题，为后续ros2 C++开发提供支持
echo "$(python3 -c "import sherpa_onnx, os; print(os.path.join(os.path.dirname(sherpa_onnx.__file__), 'lib'))")" | sudo tee /etc/ld.so.conf.d/sherpa_onnx.conf
sudo ldconfig

# 5. 检查是否开启rknn支持，具体检查是否具有librknnrt.so库，若没有则参考连接手动安装
ldd $(which sherpa-onnx)
# 查看当前rknnrt版本，实测2.3.0版本可用无报错
strings /lib/librknnrt.so | grep "librknnrt version"
```

(https://imgloc.com/image/ylDRYF)

### 下载预训练模型并终端测试

**参考：**[pre-trained models for RKNPU](https://k2-fsa.github.io/sherpa/onnx/rknn/models.html#)

```shell
# 1> 方式1：在线下载文件
wget https://github.com/k2-fsa/sherpa-onnx/releases/download/asr-models/sherpa-onnx-rk3588-streaming-zipformer-small-bilingual-zh-en-2023-02-16.tar.bz2

# 2> 方式2：直接复制文件到/opt/sherpa-onnx/目录下
cp /mnt/nfs/hy_ros/source/0.RK3588S/1.sherpa-onnx/sherpa-onnx-rknn-stream/sherpa-onnx-rk3588-streaming-zipformer-small-bilingual-zh-en-2023-02-16.tar.bz2 /opt/sherpa-onnx/

# 2. 解压文件
tar xvf sherpa-onnx-rk3588-streaming-zipformer-small-bilingual-zh-en-2023-02-16.tar.bz2
rm sherpa-onnx-rk3588-streaming-zipformer-small-bilingual-zh-en-2023-02-16.tar.bz2

# 3. 可监控rknpu加载状态
watch -n 0.5 cat /sys/kernel/debug/rknpu/load

# 4. 解码文件,查看是否正常工作
sherpa-onnx \
  --provider=rknn \
  --encoder=./sherpa-onnx-rk3588-streaming-zipformer-small-bilingual-zh-en-2023-02-16/encoder.rknn \
  --decoder=./sherpa-onnx-rk3588-streaming-zipformer-small-bilingual-zh-en-2023-02-16/decoder.rknn \
  --joiner=./sherpa-onnx-rk3588-streaming-zipformer-small-bilingual-zh-en-2023-02-16/joiner.rknn \
  --tokens=./sherpa-onnx-rk3588-streaming-zipformer-small-bilingual-zh-en-2023-02-16/tokens.txt \
  ./sherpa-onnx-rk3588-streaming-zipformer-small-bilingual-zh-en-2023-02-16/test_wavs/4.wav

# 5. 实时音频测试
sherpa-onnx-alsa \
  --provider=rknn \
  --encoder=./sherpa-onnx-rk3588-streaming-zipformer-small-bilingual-zh-en-2023-02-16/encoder.rknn \
  --decoder=./sherpa-onnx-rk3588-streaming-zipformer-small-bilingual-zh-en-2023-02-16/decoder.rknn \
  --joiner=./sherpa-onnx-rk3588-streaming-zipformer-small-bilingual-zh-en-2023-02-16/joiner.rknn \
  --tokens=./sherpa-onnx-rk3588-streaming-zipformer-small-bilingual-zh-en-2023-02-16/tokens.txt \
  plughw:3,0
```

(https://imgloc.com/image/ylDg1m)

(https://imgloc.com/image/ylDqT9)

## 2. 部署 RKLLM Qwen3-VL-2B 模型

**参考：**

- [RKLLM 模型转换](https://doc.embedfire.com/linux/rk356x/Ai/zh/latest/lubancat_ai/example/qwen2_vl.html)
- [Qwen-VL-2B 部署 RK3588S](https://blog.csdn.net/lajuchenghui/article/details/150111489)

```shell
# 1. 安装OpenCV库，Qwen3-VL-2B ROS功能包多模态输入需求库
sudo apt-get install libopencv-dev python3-opencv # 安装 OpenCV 库

# 2.新建目录
mkdir /opt/rknn-llm
cd /opt/rknn-llm
# 上传rknn-llm-release-v1.2.1.zip到/opt/rknn-llm/目录下
cp /mnt/nfs/hy_ros/source/0.RK3588S/2.rknn-llm/rknn-llm.zip /opt/rknn-llm/
unzip rknn-llm.zip
rm rknn-llm.zip

# 3.进入multimodal_model_demo/deploy目录
cd /opt/rknn-llm/rknn-llm/examples/multimodal_model_demo/deploy
chmod +x build-linux.sh
./build-linux.sh

# 4.更新librkllmrt.so库，为后续ros2 C++开发提供支持
cp /opt/rknn-llm/rknn-llm/rkllm-runtime/Linux/librkllm_api/aarch64/librkllmrt.so /lib/
chmod +x /lib/librkllmrt.so

# 5. 更新rkllm.h头文件，为后续ros2 C++开发提供支持
cp /opt/rknn-llm/rknn-llm/rkllm-runtime/Linux/librkllm_api/include/rkllm.h /usr/include/
cp /opt/rknn-llm/rknn-llm/examples/multimodal_model_demo/deploy/3rdparty/librknnrt/Linux/librknn_api/include/rknn_api.h /usr/include/
sudo ldconfig
ls -l /usr/include/rkllm.h
ls -l /usr/include/rknn_api.h

# 6.复制rkllm模型文件
cd install/demo_Linux_aarch64

# 复制模型文件到示例目录
cp /mnt/nfs/hy_ros/source/0.RK3588S/2.rknn-llm/qwen3-vl-2b_vision_rk3588.rknn /opt/rknn-llm/
cp /mnt/nfs/hy_ros/source/0.RK3588S/2.rknn-llm/qwen3-vl-2b-instruct_w8a8_rk3588.rkllm /opt/rknn-llm/
chmod +x /opt/rknn-llm/qwen*

# 7.设置环境变量
export LD_LIBRARY_PATH=./lib

# 8. 运行示例
./demo demo.jpg /opt/rknn-llm/qwen3-vl-2b_vision_rk3588.rknn /opt/rknn-llm/qwen3-vl-2b-instruct_w8a8_rk3588.rkllm 2048 4096 3
```

(https://imgloc.com/image/ylD5Qc)

(https://imgloc.com/image/ylDef6)

## 3. 部署百度大模型音色复刻 TTS

**参考：**[百度大模型音色复刻 TTS](https://cloud.baidu.com/doc/SPEECH/s/Am8wytft2)

1. 安装必要的 python 库

   ```{note}
   主机侧和端侧均需要安装，音色管理创建等操作可以在主机侧进行。
   ```

   ```shell
   # 安装异步 http 库和 websockets 库
   sudo apt-get install python3-aiohttp python3-websockets
   ```

2. 复刻本人音色，需录制 15s 任意文本音频，并转换为 base64 编码的 mp3 格式

   - [在线转换工具](https://www.toolfk.com/en/tools/audio-to-base64.html)
   - 下载 base64.txt 文件，替换 `hy_ros/src/audio_tts/audio_tts/base64.txt`

3. 复刻机器人音色，可直接使用 `hy_ros/src/audio_tts/audio_tts/base64_robot.txt`

   ```{tip}
   机器人音色可以直接修改文件 `hy_ros/src/audio_tts/audio_tts/tts_api.py` 中的 `base64_file_path` 变量为 `base64_robot.txt`。
   ```

4. 获取 API key

   - 参考[百度大模型应用创建](https://ai.baidu.com/ai-doc/REFERENCE/Bkru0l60m)创建应用配置百度智能云 api 密钥，Server Key
   - 更新到秘钥到 `hy_ros/src/audio_tts/launch/audio_tts_launch.py` 文件中和 `tts_api.py` 文件中
   - 设置 `tts_api.py` 文件中的 `run_create_voice` 变量为 True，表示在运行时创建 Voice ID

5. 创建 Voice ID

   ```{note}
   可直接在主机侧运行创建并更新 Voice ID。
   ```

   - 在 `hy_ros/src/audio_tts/audio_tts` 目录下运行 `python3 tts_api.py`
   - 查看并记录返回的 Voice ID
   - 更新秘钥、音色 ID 到 `hy_ros/src/audio_tts/launch/audio_tts_launch.py` 文件中

6. 音色管理

   - 设置 `tts_api.py` 文件中的 `run_tts` 变量为 True，表示在运行时使用音色复刻 TTS 进行测试
   - 设置 `tts_api.py` 文件中的 `run_list_voice` 变量为 True，表示在运行时查看 Voice ID 列表
   - 设置 `tts_api.py` 文件中的 `run_query_detail` 变量为 True，表示在运行时查看 Voice ID 详情
   - 设置 `tts_api.py` 文件中的 `run_delete_voice` 变量为 True，表示在运行时删除 Voice ID

(https://imgloc.com/image/ylD9td)

(https://imgloc.com/image/ylDMyg)

# 四、Foxglove Web 可视化配置

## 1. 端侧部署 (RK3588S)

Foxglove Bridge 用于将 ROS 2 话题通过 WebSocket 转发给 Foxglove Studio。

```bash
# 配置 joint_state_publisher,实现关节状态发布
sudo apt-get install -y ros-humble-joint-state-publisher
# 配置 foxglove_bridge,实现话题转发
sudo apt-get install -y ros-humble-foxglove-bridge
# 配置 RTSP 转 WebRTC 网关，使用 go2rtc 拉取硬件编码 RTSP 流
```

## 2. 上位机连接 (PC/iPad)

1. 打开 [Foxglove Studio](https://foxglove.dev/) (网页版或客户端)。
2. 点击 **"Open Connection"**。
3. 选择 **"Foxglove WebSocket"** 协议。
4. 输入端侧地址：`ws://192.168.22.219:8765` (IP 根据实际情况调整)。
5. 连接成功后即可订阅和查看端侧的所有话题。

(https://imgloc.com/image/ylDPg0)

# 五、 yolov8 目标检测模型训练

如果希望自己训练 yolov8 黄油或其他目标检测模型，以下教程可提供参考。

## 1. 数据集准备

1. 运行 `tools/capture_tool.py` 采集数据集，采集到的图像会保存到 `source/butter_img` 目录下。（建议采集 300 张以上图像）

2. 使用 [roboflow](https://app.roboflow.com) 平台实现数据集标注和管理。

```{tip}
本次训练使用 60% 网络数据集 + 40% 个人自定义数据集 [butter_robot_dataset](https://universe.roboflow.com/butter-robot/butter_robot)，可自行下载删除修改。
```

(https://imgloc.com/image/ylDQYY)

(https://imgloc.com/image/ylDW3b)

(https://imgloc.com/image/ylD2T1)

3. 数据集预处理包括数据增强、数据划分，下载 yolov8 数据集配置文件。

(https://imgloc.com/image/ylDJuL)

## 2. Win 环境实现模型训练

### 2.1 配置虚拟环境

1. 初始化 uv 项目

```powershell
# 安装uv
pip3 install uv
# 查看python版本
uv python list
# 选择python版本创建虚拟环境项目
uv init -p 3.12 butter_train_env
cd butter_train_env
```

2. 添加依赖

```powershell
uv add pandas  # 安装pandas库
uv add onnxscript  # 安装onnxscript库，用于转换模型
uv add --dev ipykernel  # 安装ipykernel库，用于在Jupyter中选择项目内核
```

3. 创建并注册项目内核

在项目虚拟环境下注册一个可在 Jupyter/Trae 中选择的内核：

```powershell
.venv\Scripts\python -m ipykernel install --user --name butter_train --display-name "Python (butter_train)"
```

完成后，系统目录 `C:\Users\<你的用户名>\AppData\Roaming\jupyter\kernels\butter_train` 会出现对应的 `kernelspec`。

4. 在 VSCode 或者 Pycharm IDE 中选择内核

打开 Notebook，使用右上角的内核选择器切换到：`Python (butter_train)`。选择后，`import pandas as pd` 即可在该项目环境中正常使用。

5. UV 常用命令

```shell
uv tree  # 查看项目依赖树
uv sync  # 根据 `pyproject.toml` 同步安装依赖到 `.venv`
uv sync --no-dev  # 仅安装非开发依赖
uv add 'pandas==2.31.0'  # 安装指定版本的 pandas 到项目环境
uv add -r requirements.txt  # 根据 `requirements.txt` 安装非开发依赖
uv add --dev ipykernel  # 包仅会被加入到开发环境的分组中
```

### 2.2 安装 torch-gpu

1. 确认 CUDA 版本以及安装 CUDA 和 cuDNN 版本

参考：[CUDA 和 cuDNN 安装](https://blog.csdn.net/sinat_26398509/article/details/143566753)

2. UV 安装 torch-gpu

参考：[torch-gpu 安装](https://blog.csdn.net/Humbunklung/article/details/146046406)

```text
# 测试环境
显卡：Nvida GeForce RTX 4070 Super
CUDA 版本：13.1
CUDA Toolkit 版本 13.0
cuDNN 版本：9.11.0
pytorch-gpu 版本：2.9.1
```

### 2.3 安装 ultralytics

安装 ultralytics 库，测试 yolov8n 预训练参数是否成功加载到 GPU。

```{important}
必须使用 ultralytics rknn 修改版才能正确导出 RKNN 模型，且依然可以通过 UV 进行管理。
```

```shell
# 安装适配 RKNN 的 ultralytics 库（airockchip 维护版本）
# 注意：必须使用此修改版才能正确导出 RKNN 模型，且依然可以通过 UV 进行管理
uv add git+https://github.com/airockchip/ultralytics_yolov8.git
```

pyproject.toml 配置文件可参考如下：

```toml
# UV配置文件仅供参考，实际使用时请根据自己的环境进行修改
[project]
name = "butter-train-env"
version = "0.1.0"
description = "Add your description here"
readme = "README.md"
requires-python = ">=3.12"
dependencies = [
    "onnxscript>=0.5.0",
    "pandas>=2.3.3",
    "tensorboard>=2.20.0",
    "torch==2.5.1",
    "torchaudio==2.5.1",
    "torchvision==0.20.1",
    "ultralytics",
]

[tool.uv.sources]
torch = [
  { index = "pytorch-cu124", marker = "sys_platform == 'linux' or sys_platform == 'win32'" },
]
torchvision = [
  { index = "pytorch-cu124", marker = "sys_platform == 'linux' or sys_platform == 'win32'" },
]
torchaudio = [
  { index = "pytorch-cu124", marker = "sys_platform == 'linux' or sys_platform == 'win32'" },
]
ultralytics = { git = "https://github.com/airockchip/ultralytics_yolov8.git" }

[[tool.uv.index]]
name = "pytorch-cu124"
url = "https://download.pytorch.org/whl/cu124"
explicit = true

[dependency-groups]
dev = [
    "ipykernel>=7.1.0",
]
```

```python
# 测试安装是否全部成功
import torch
import ultralytics
from ultralytics import YOLO

# 验证PyTorch GPU可用性
print("PyTorch GPU可用：", torch.cuda.is_available())
print("CUDA版本：", torch.__version__)
# 验证Ultralytics版本及GPU适配
print("Ultralytics版本：", ultralytics.__version__)
# 加载YOLOv8n并指定GPU
model = YOLO("yolov8n.pt")
model.to("cuda:0")
print("YOLOv8n已加载到GPU：", next(model.model.parameters()).is_cuda)
```

(https://imgloc.com/image/ylD4eM)

### 2.4 yolov8n 模型训练和转换

```python
# 开始训练
# data: 数据集配置文件路径 (使用绝对路径避免错误)
# epochs: 训练轮数
# imgsz: 输入图像大小
# batch: 批次大小
# device: 训练设备 (0 表示使用第一块 GPU)
results = model.train(
    data="C:/Users/Administrator/Desktop/butter_yolov8n_train/Dataset/data.yaml",
    epochs=120,
    imgsz=640,
    batch=32,
    device=0,
    project="butter_train_results",
    name="yolov8n_butter",
    exist_ok=True,  # 允许覆盖同名目录，方便调试
    verbose=True,  # 显示详细训练日志
)
```

```shell
# 启动 tensorboard 可视化训练过程
cd butter_train_env
uv run tensorboard --logdir ../butter_train_results/yolov8n_butter --port 6006
```

| 数据类别 | 指标 / 损失名称 | 最终数值 | 单位 | 备注 |
| :---: | :---: | :---: | :--: | :--- |
|  **Metrics 检测指标** | mAP50(B) |  92.56%  |  - | IoU≥0.5 时的平均精度 |
| | mAP50-95(B) |  75.70%  |  - | IoU 从 0.5 到 0.95 的平均精度 |
| |  Precision(B) |  89.25%  |  - | 预测为黄油的精准度 |
| | Recall(B) |  87.58%  |  - | 实际黄油的召回率 |
| **训练集（Train）损失** | box_loss |  0.2732  |  - | 预测框位置损失 |
| | cls_loss |  0.1944  |  - | 黄油类别预测损失 |
| | dfl_loss |  0.8377  |  - | 框分布拟合损失 |
|  **验证集（Val）损失**  | box_loss |  0.7615  |  - | 预测框位置损失 |
| | cls_loss |  0.7156  |  - | 黄油类别预测损失 |
| | dfl_loss |  1.3528  |  - | 框分布拟合损失 |

(https://imgloc.com/image/ylDEKr)

(https://imgloc.com/image/ylDlyh)

```python
from ultralytics import YOLO
# 1. 加载训练好的最佳权重文件
model_path = "butter_train_results/yolov8n_butter/weights/best.pt"
model = YOLO(model_path)
# 2. 导出为 RKNN 兼容的 ONNX 模型
# 关键参数说明：
# format='rknn': 指定导出格式为 rknn (实际上会先导出为特殊的 onnx)
success = model.export(format="rknn")
print(f"导出完成: {success}")
```

```{warning}
必须使用 ultralytics rknn 修改版才能正确导出 RKNN 模型，导出的模型必须是唯一的 .onnx 文件。
```

(https://imgloc.com/image/ylDtge)

## 3. Ubuntu 环境实现模型转换

### 3.1 docker 安装 RKNN-Toolkit2

因为在宿主机配置 RKNN-Toolkit2 环境极易出错，所以建议在 Ubuntu 环境下使用 Docker 容器来运行 RKNN-Toolkit2。

1. 下载并安装 Docker

```shell
# 1. 安装Docker并配置自启
sudo apt update -y

# 安装apt依赖工具（允许HTTPS访问仓库、解压缩等）
sudo apt install -y ca-certificates curl gnupg lsb-release git

# 创建密钥存储目录
sudo mkdir -p /etc/apt/trusted.gpg.d

# 下载并添加Docker官方GPG密钥（使用阿里云镜像修复SSL连接问题）
curl -fsSL https://mirrors.aliyun.com/docker-ce/linux/ubuntu/gpg | sudo gpg --dearmor -o /etc/apt/trusted.gpg.d/docker.gpg

# 配置Docker仓库源（使用阿里云镜像加速）
echo \
  "deb [arch=$(dpkg --print-architecture) signed-by=/etc/apt/trusted.gpg.d/docker.gpg] https://mirrors.aliyun.com/docker-ce/linux/ubuntu \
  $(lsb_release -cs) stable" | sudo tee /etc/apt/sources.list.d/docker.list > /dev/null

# 更新软件包索引
sudo apt update

# 安装Docker核心组件（engine+cli+containerd）
sudo apt install -y docker-ce docker-ce-cli containerd.io

# 启动Docker服务（若未自动启动）
sudo systemctl start docker

# 设置Docker开机自启
sudo systemctl enable docker

# 配置 Docker 镜像加速（解决拉取镜像失败/速度慢的问题）
sudo mkdir -p /etc/docker
sudo tee /etc/docker/daemon.json <<-'EOF'
{
  "registry-mirrors": [
    "https://docker.m.daocloud.io",
    "https://huecker.io"
  ]
}
EOF
sudo systemctl daemon-reload
sudo systemctl restart docker

# 验证Docker是否正常运行（输出"Hello from Docker!"即成功）
sudo docker run --rm hello-world

# 将当前用户添加到docker组
sudo usermod -aG docker $USER

# 刷新组权限（无需重启，立即生效）
newgrp docker

# 验证：无需sudo执行docker命令
docker ps
```

(https://imgloc.com/image/ylDKoa)

2. 下载 rknn-toolkit2 的 Dockerfile

```shell
# 1. 下载 rknn-toolkit2 的 Dockerfile
# 创建目录并进入
sudo mkdir -p /opt/rknn-toolkit2/tools-file
cd /opt/rknn-toolkit2/tools-file

# 克隆仓库（使用 Gitee 镜像加速下载）
sudo git clone https://gitee.com/cddssgl/rknn-toolkit2.git
cd rknn-toolkit2/rknn-toolkit2/docker/docker_file/ubuntu_20_04_cp38

# 2. 修改 Dockerfile 源（解决 pip 安装依赖失败问题）
sudo sed -i 's|mirror.baidu.com|mirrors.aliyun.com|g' Dockerfile_ubuntu_20_04_for_cp38

# 3. 构建镜像
sudo docker build -f Dockerfile_ubuntu_20_04_for_cp38 -t rknn-toolkit2:cp38-2.3.2 .

# 4. 验证镜像是否构建成功
sudo docker images | grep rknn-toolkit2:cp38-2.3.2
```

(https://imgloc.com/image/ylDGWC)

3. 挂载启动 docker 容器

```shell
# 1.先创建本地工作目录
sudo mkdir -p /opt/rknn-toolkit2/workspace
cd /opt/rknn-toolkit2/workspace

# 2.启动命令（挂载本地目录+映射 8888 端口）
sudo docker run -it --privileged --rm \
  -v /opt/rknn-toolkit2/workspace:/root/workspace \
  -p 8888:8888 \
  --name rknn-cp38-container \
  rknn-toolkit2:cp38-2.3.2 /bin/bash

# 3.进入容器后执行以下命令
python3 --version
python3 -c "from rknn.api import RKNN; print('RKNN 导入成功！版本：2.3.2')"
```

(https://imgloc.com/image/ylDmu4)

4. 常用容器管理命令

```shell
# 1. 列出运行中的容器
docker ps

# 2. 停止容器（替换为容器名称/ID）
docker stop rknn-cp38-container

# 3. 重新启动已停止的容器
docker start rknn-cp38-container

# 4. 进入已运行的容器（再次打开终端）
docker exec -it rknn-cp38-container /bin/bash

# 5. 删除镜像（无需使用时清理磁盘空间）
docker rmi rknn-toolkit2:cp38-2.3.2
```

### 3.2 转换模型

```{note}
此时环境为 Ubuntu 主机环境，容器只是用于执行转换脚本，所有模型文件挂载在主机目录下 `/opt/rknn-toolkit2/workspace` 中。
```

```shell
# 1. 克隆 rknn_model_zoo 仓库，使用脚本文件转换模型
cd /opt/rknn-toolkit2/workspace
sudo git clone https://gitee.com/airockchip/rknn_model_zoo.git

cd rknn_model_zoo/examples/yolov8/python

# 2. 上传模型文件和黄油图片到ubuntu目录
chmod +x best.onnx
sudo cp best.onnx /opt/rknn-toolkit2/workspace/rknn_model_zoo/examples/yolov8/python/
```

```{note}
下面环境为 rknn-toolkit2:cp38-2.3.2 容器内，需要在容器内执行转换脚本。
```

```shell
cd /root/workspace/rknn_model_zoo/examples/yolov8/python
# pip uninstall onnx  # (可选)：可能会因为onnx版本过高导致转换失败
# pip install "onnx==1.14.1" # (可选)
python convert.py best.onnx rk3588

# 转换完成后，将模型文件复制到主机目录下
cd /root/workspace/rknn_model_zoo/examples/yolov8/model
sudo cp yolov8n.rknn /home/k/
```

(https://imgloc.com/image/ylDXKH)

(https://imgloc.com/image/ylD3gX)

## 4. 端侧测试

```{note}
下面环境为端侧环境，使用 RKNN-Toolkit-Lite2 python 接口测试模型。
```

```shell
# 1. 安装 RKNN-Toolkit-Lite2 python 包
pip3 install rknn-toolkit-lite2

# 2. 测试是否安装成功
python3 -c "from rknnlite.api import RKNNLite; print('RKNNLite 导入成功！版本：2.3.2')"

# 3. 上传模型文件和测试图片到端侧目录
mkdir -p /opt/rknn-toolkit2-lite
cd /opt/rknn-toolkit2-lite

cp /mnt/nfs/hy_ros/source/0.RK3588S/3.butter_yolov8n/yolov8.rknn /opt/rknn-toolkit2-lite/
cp /mnt/nfs/hy_ros/source/0.RK3588S/3.butter_yolov8n/butter.jpg /opt/rknn-toolkit2-lite/
cp /mnt/nfs/hy_ros/source/0.RK3588S/3.butter_yolov8n/test.py /opt/rknn-toolkit2-lite/

# 4. 运行测试脚本
python3 test.py
```

(https://imgloc.com/image/ylDiNF)

## 5. 人手跟随(拓展)

### 5.1 基本原理

### 5.2 模型部署

# 六、yolov8n 目标检测部署

## 1. 基本原理

整个 **rk_camera** 到 **rk_inference** 再到 **rk_streamer** 的流程设计，充分利用了 RK3588S 的异构计算架构（ISP、RGA、NPU、VPU），实现了端到端的低延迟和高效处理。利用 ROS2 的组件设计，使用 UniquePtr 实现多个节点之间的零拷贝数据传输，避免了 CPU 拷贝带来的性能损失，可大幅提升系统吞吐量。

**节点 1: rk_camera (采集)**

| **流程描述** | **关键代码 / 工具** | **触发的硬件** | **硬件功能** |
| --- | --- | --- | --- |
| **GStreamer 抓取** | v4l2src (GStreamer 插件) | **ISP** | 摄像头传感器进来的数据是 Raw 格式，**ISP** 硬件自动将其去噪、白平衡、去马赛克，输出 NV12 数据。 |
| **数据传输** | 内核驱动层 (V4L2 Driver) | **DMA** | **DMA** 硬件悄悄地把 ISP 处理好的数据搬运到内存（RAM）中，CPU 此时在休息。 |
| **拷贝到 ROS msg** | memcpy (C++ 标准库) | **CPU** | **这里是唯一的 CPU 重活**。CPU 把 GStreamer 的 Buffer 里的数据拷贝到 ROS 消息的 std::vector 中。（注：这是为了生成 ROS 消息，后续传输才是零拷贝）。 |
| **发布消息** | pub->publish(std::move(msg)) | **(无)** | 这是一个软件行为。std::move 转移了指针所有权，**避免了** CPU 进行节点间的数据拷贝。 |

**节点 2: rk_inference (推理与绘图 -- 核心)**

| **流程描述** | **关键代码 / 工具** | **触发的硬件** | **硬件在做什么？** |
| --- | --- | --- | --- |
| **准备 Buffer** | wrapbuffer_virtualaddr(...) | **(无)** | 纯软件动作。只是告诉 RGA 驱动："数据在这个内存地址，你记一下"。 |
| **缩放 + 格式转换** | **imresize(src, dst)** 或 imcvtcolor (librga 库) | **RGA** | **核心触发点！** 这行代码向 RGA 寄存器发送指令。**RGA 硬件**启动，瞬间把 1080P NV12 读入，处理成 640x640 RGB，写回内存。CPU 等待或做别的事。 |
| **NPU 推理** | **rknn_run(ctx, ...)** (rknn_api 库) | **NPU** | **核心触发点！** 这行代码唤醒 **NPU 硬件**。NPU 加载模型权重，对 640x640 的数据进行数万亿次矩阵运算。 |
| **后处理** | if (conf > 0.5) ... (C++ 逻辑) | **CPU** | 解析 NPU 输出的浮点数，计算坐标 (x,y,w,h)。这是简单的逻辑判断，CPU 做这个很快。 |
| **RGA 绘图** | **imdrawrect(src, rect, ...)** (librga 库) | **RGA** | **核心触发点！** 代码告诉 **RGA 硬件**："在 src 这个 NV12 图片的 (x,y) 位置，把像素值改成红色"。RGA 直接修改内存，不用 CPU 逐个像素去画。 |
| **发布** | pub->publish(std::move(msg)) | **(无)** | 指针传递，零拷贝。 |

**节点 3: rk_streamer (推流)**

| **流程描述** | **关键代码 / 工具** | **触发的硬件** | **硬件在做什么？** |
| --- | --- | --- | --- |
| **写入管道** | writer.write(image) (OpenCV) -> appsrc | **CPU/DMA** | 数据进入 GStreamer 的管道系统。 |
| **硬件编码** | Pipeline 字符串中的 **mpph264enc** | **VPU (RKVENC)** | **核心触发点！** mpph264enc 插件调用 MPP 库，MPP 库驱动 **VPU 硬件**。VPU 读取 NV12 原始数据，根据 H.264 算法进行帧内预测、运动估计，输出压缩后的码流。 |
| **网络发送** | rtspclientsink | **CPU/网卡** | CPU 将压缩好的小数据包通过网络协议栈发给网卡。 |

## 2. 端侧依赖安装

在 RK3588S 端侧（Ubuntu 系统）上，需要安装以下基础库：

### 2.1 安装 GStreamer 和 rga

```bash
# 1. 安装 GStreamer 及其插件（包含 app 库）
sudo sed -i 's/mirrors.tuna.tsinghua.edu.cn/mirrors.ustc.edu.cn/g' /etc/apt/sources.list
sudo apt-get update

# 编译安装 Rockchip 多媒体组件
sudo apt-get install -y --fix-missing gcc g++ cmake meson ninja-build \
    libdrm-dev libgstreamer1.0-dev libgstreamer-plugins-base1.0-dev \
    gstreamer1.0-plugins-base gstreamer1.0-plugins-good \
    gstreamer1.0-plugins-bad gstreamer1.0-plugins-ugly \
    gstreamer1.0-tools gstreamer1.0-rtsp

# 2. 创建工作目录
sudo mkdir -p /opt/rk_multimedia
sudo chown $USER:$USER /opt/rk_multimedia
cd /opt/rk_multimedia

# 3. 编译安装 MPP (Media Process Platform)
git clone https://github.com/rockchip-linux/mpp.git --depth=1
cd mpp
cd build
cmake -DCMAKE_INSTALL_PREFIX=/usr -DCMAKE_BUILD_TYPE=Release ..
make -j$(nproc)
sudo make install
sudo ldconfig
cd ../..

# 4. 安装 librga (使用预编译库)
git clone https://gitee.com/airockchip/librga.git --depth=1
cd librga
sudo cp -r include/* /usr/local/include/
sudo cp -r libs/Linux/gcc-aarch64/* /usr/local/lib/

# 手动创建 pkgconfig 文件
sudo mkdir -p /usr/local/lib/pkgconfig
sudo tee /usr/local/lib/pkgconfig/librga.pc > /dev/null <<EOF
prefix=/usr/local
exec_prefix=\${prefix}
libdir=\${exec_prefix}/lib
includedir=\${prefix}/include

Name: librga
Description: Rockchip RGA 2D graphics acceleration library
Version: 1.10.0
Libs: -L\${libdir} -lrga
Cflags: -I\${includedir}
EOF

sudo ldconfig
cd ..

# 5. 编译安装 gstreamer-rockchip 插件
git clone https://gitee.com/emancipator/gstreamer-rockchip.git gstreamer-rockchip
cd gstreamer-rockchip
export PKG_CONFIG_PATH=/usr/local/lib/pkgconfig:$PKG_CONFIG_PATH
meson setup build --prefix=/usr --buildtype=release
ninja -C build
sudo ninja -C build install

# 6. 更新库缓存并验证
gst-inspect-1.0 | grep mpp
```

### 2.2 安装 RTSP 推流服务器

```bash
# 1. 安装 ROS2 依赖
sudo apt-get install -y ros-humble-image-transport ros-humble-cv-bridge

# 2. 安装 RTSP 推流服务器 (go2rtc)
wget https://github.com/AlexxIT/go2rtc/releases/latest/download/go2rtc_linux_arm64 -O /usr/local/bin/go2rtc
chmod +x /usr/local/bin/go2rtc

# 3. 创建配置文件 /etc/go2rtc.yaml
sudo bash -c 'cat <<EOF > /etc/go2rtc.yaml
streams:
  camera: null

api:
  listen: ":1984"

rtsp:
  listen: ":8554"

webrtc:
  listen: ":8555"
  candidates:
    - 192.168.22.219:8555 # 请修改为你的板卡实际 IP
EOF'

# 4. 设置go2rtc开机自启动 (Systemd 服务)
sudo bash -c 'cat <<EOF > /etc/systemd/system/go2rtc.service
[Unit]
Description=Go2RTC Media Server
After=network.target

[Service]
ExecStart=/usr/local/bin/go2rtc -c /etc/go2rtc.yaml
WorkingDirectory=/etc
Restart=always
User=root

[Install]
WantedBy=multi-user.target
EOF'

# 5. 启用并启动服务
sudo systemctl daemon-reload
sudo systemctl enable go2rtc
sudo systemctl start go2rtc
```

## 3. RKNN-NPU 部署

在进行 NPU 推理开发前，必须确保系统已启用 RGA 硬件加速驱动，并安装了用户态库文件 (`librga`)。
RGA (Raster Graphic Acceleration Unit)是一个独立的 2D 硬件加速器，可用于加速点/线绘制，执行图像缩放、旋转、bitBlt、alpha 混合等常见的 2D 图形操作。

(https://imgloc.com/image/ylMjpO)

## 4. RTSP 推流

当 `rk_streamer` 正常运行后，它会主动将视频流推送到 `rtsp://127.0.0.1:8554/camera`。
在网页输入 `http://192.168.22.219:1984/stream.html?src=camera` 即可查看推流视频。

(https://imgloc.com/image/ylMbvL)

# 七、SLAM 部署

本节介绍如何在端侧 RK3588S 上部署 SLAM 建图功能，包括在线建图、地图发布与雷达数据裁剪。

## 1. 安装依赖

在端侧（RK3588S）执行以下命令安装必要功能包：

```bash
sudo apt update
sudo apt install -y ros-humble-slam-toolbox ros-humble-navigation2 \
    ros-humble-nav2-bringup ros-humble-laser-filters \
    ros-humble-robot-localization
```

## 2. 配置功能包

为了实现"在线建图"、"发布 map->odom 变换"以及"雷达后方裁剪"的功能，需进行以下配置。

### 2.1 雷达数据裁剪 (Laser Filters)

为解决机器人后方遮挡问题（例如自身结构遮挡），需配置 `laser_filters` 对雷达数据进行裁剪。
新建配置文件 `src/hy_slam/config/laser_filter.yaml`：

```yaml
scan_to_scan_filter_chain:
  ros__parameters:
    filter1:
      name: rear_box_filter
      type: laser_filters/LaserScanBoxFilter
      params:
        box_frame: base_link
        max_x: -0.1
        min_x: -1.0
        max_y: 0.3
        min_y: -0.3
        max_z: 1.0
        min_z: -1.0
        invert: false
```

### 2.2 SLAM 配置 (Slam Toolbox)

配置 `slam_toolbox` 进行在线建图与地图发布。`slam_toolbox` 在 mapping 模式下会自动发布 `map` -> `odom` 的 TF 变换。
新建配置文件 `src/hy_slam/config/mapper_params_online_async.yaml`

```yaml
slam_toolbox:
  ros__parameters:
    odom_frame: odom
    map_frame: map
    base_frame: base_link
    scan_topic: /scan_filtered # 注意：订阅经过裁剪后的雷达话题
    mode: mapping

    # 更多参数参考模板...
    use_scan_matching: true
    map_update_interval: 5.0
    resolution: 0.05
```

### 2.3 定位参数配置 (Slam Toolbox)

配置 `slam_toolbox` 进行定位。`slam_toolbox` 在 localization 模式下会根据静态地图与实时雷达数据进行匹配，发布 `map` -> `odom` 的 TF 变换。
新建配置文件 `src/hy_slam/config/mapper_params_localization.yaml`

```yaml
slam_toolbox:
  ros__parameters:
    odom_frame: odom
    map_frame: map
    base_frame: base_link
    scan_topic: /scan_filtered
    mode: localization

    # 更多参数参考模板...
    use_scan_matching: true
    map_update_interval: 5.0
    resolution: 0.05
```

## 3. SLAM 在线建图/存图

- `slam.launch.py` 启动 SLAM 建图功能，实现在线建图。调用 `save_map.sh` 脚本保存地图。
- `localization.launch.py` 启动雷达数据裁剪+定位功能，根据静态地图与实时雷达数据进行匹配，发布 `map` -> `odom` 的 TF 变换。
- `laser_filters.launch.py` 仅启动雷达数据裁剪功能，将 `/scan` 话题裁剪为 `/scan_filtered`，依赖 Nav2 功能包的 AMCL + Map Server，发布 `map` -> `odom` 的 TF 变换。

1. 启动雷达功能包

```bash
cd ~/hy_linux/nfs/hy_ros

# 注意：若未配置udev规则，请先执行，然后重新插拔雷达
sudo bash src/ldlidar_driver_ros2/scripts/Ldlidar_udev.sh

# 1. 编译
colcon build --packages-select ldlidar_driver_ros2

# 2. 运行雷达
source install/setup.bash
ros2 launch ldlidar_driver_ros2 ldlidar_driver.launch.py
```

2. 启动 SLAM 建图功能

```bash
# 编译
cd ~/hy_linux/nfs/hy_ros
colcon build --packages-select hy_slam

# 运行
source install/setup.bash
ros2 launch hy_slam slam.launch.py
```

3. 保存地图

```{warning}
请在 `slam.launch.py` 仍在运行时执行保存脚本。若先终止 SLAM 程序，内存中的地图数据将丢失，导致无法保存。
```

完成建图后，打开一个新的终端执行以下脚本：

```bash
# 默认保存为 my_map
cd ~/hy_linux/nfs/hy_ros
./src/hy_slam/scripts/save_map.sh

# 或指定地图名
# ./src/hy_slam/scripts/save_map.sh room_1
```

地图将保存至 `install/hy_slam/share/hy_slam/map/` 目录下（包含 `.pgm` 和 `.yaml` 两个文件）。

## 4. 可视化调试 (Foxglove)

使用 Foxglove Studio 查看实时建图效果。

1. **客户端连接**：
   - 在 PC 上打开 Foxglove Studio。
   - 选择 **Open Connection** -> **Foxglove WebSocket**。
   - 地址输入：`ws://<机器人IP>:8765`。

2. **配置面板**：
   - 添加 **2D Panel**。
   - 在左侧 Topics 勾选：
     - `/map` (SLAM 地图)
     - `/scan` (原始雷达)
     - `/scan_filtered` (裁剪后雷达)
     - TF 树 (确保 `map` -> `odom` -> `base_link` -> `radar_Link` 连通)。

/scan 雷达数据可视化

(https://imgloc.com/image/ylMzsx)

/map 地图可视化

(https://imgloc.com/image/ylMq4e)

## 5. 定位模式

若已构建地图，可切换至纯定位模式运行（不再更新地图，仅进行定位）：

1. **方式一：使用 slam_toolbox 进行定位**

   该模式下，`slam_toolbox` 会加载静态地图，并将实时雷达数据与地图匹配，发布 `map` -> `odom` 变换。

   ```bash
   # 启动定位模式（默认加载 my_map）
   ros2 launch hy_slam localization.launch.py
   ```

2. **方式二：使用 Nav2 (AMCL) 进行定位**（推荐用于导航）

   若后续使用 Nav2 导航栈，通常由 `amcl` 节点负责定位，`map_server` 负责发布地图。此时 `hy_slam` 仅需提供雷达数据裁剪。

   - **步骤 1**：启动雷达滤波器（仅发布 /scan_filtered）

     ```bash
     ros2 launch hy_slam laser_filter_only.launch.py
     ```

   - **步骤 2**：启动 Nav2 (AMCL + Map Server)

     _(需在 Nav2 启动文件中配置加载 `install/hy_slam/share/hy_slam/map/my_map.yaml`)_

```{important}
无论哪种方式，定位模式下**必须**发布雷达数据 (`/scan_filtered`)。
```

# 八、Nav2 部署

本节介绍如何部署 Nav2 导航栈，实现"搜索黄油 → 导航抓取 → 返回起点"的自主任务。

## 1. 端侧安装依赖

在端侧（RK3588S）执行以下命令安装 Nav2 导航相关功能包：

```bash
sudo apt update
sudo apt install -y \
    ros-humble-navigation2 \
    ros-humble-nav2-bringup \
    ros-humble-nav2-simple-commander
```

```{important}
本章节依赖第七章 SLAM 部署的功能包（`slam-toolbox`、`robot-localization`、`laser-filters`），若未安装请先完成第七章配置。同时需要第六章的视觉检测系统、底盘通信功能包（`uart`）和里程计融合功能包（`ekf_odom`）正常运行。
```

### 1.2 前置条件检查

在开始 Nav2 部署前，请确认以下条件已满足：

- ✅ 已完成第七章 SLAM 建图，地图文件保存在 `install/hy_slam/share/hy_slam/map/`
- ✅ 已部署第六章视觉检测系统（YOLOv8 + RKNN NPU）
- ✅ 底盘串口通信正常（UART 与 ESP32S3）
- ✅ 里程计融合节点正常运行（EKF）
- ✅ 雷达数据正常发布（`/scan` 话题）

## 2. 系统架构设计

### 1.1 整体架构

导航系统采用分层设计，从上到下依次为：

```text
┌─────────────────────────────────────────────────────────┐
│  任务调度层 (Mission Layer)                              │
│  - 状态机管理 (搜索/导航/抓取/返回)                       │
│  - 目标点规划与发布                                       │
│  - 视觉检测结果订阅                                       │
└─────────────────────────────────────────────────────────┘
                         ↓
┌─────────────────────────────────────────────────────────┐
│  导航规划层 (Nav2 Stack)                                 │
│  - 全局路径规划 (NavFn)                                  │
│  - 局部轨迹规划 (DWB)                                    │
│  - 行为协调 (Behavior Tree)                              │
└─────────────────────────────────────────────────────────┘
                         ↓
┌─────────────────────────────────────────────────────────┐
│  定位感知层 (Localization & Perception)                  │
│  - AMCL 粒子滤波定位                                     │
│  - 代价地图构建 (静态层+障碍层+膨胀层)                    │
│  - 雷达数据过滤 (laser_filters)                          │
└─────────────────────────────────────────────────────────┘
                         ↓
┌─────────────────────────────────────────────────────────┐
│  执行控制层 (Control Layer)                              │
│  - 速度指令发布 (/cmd_vel)                               │
│  - 底盘运动控制 (UART → ESP32S3)                         │
│  - 舵机控制 (抓取动作)                                    │
└─────────────────────────────────────────────────────────┘
```

### 1.2 关键技术点

- **TF 坐标变换链**：`map` → `odom` → `base_link` → `laser_link`
- **零拷贝通信**：视觉检测节点与导航系统通过 ROS2 零拷贝传递目标位置
- **代价地图融合**：静态地图 + 实时雷达障碍 + 安全膨胀区域

## 2. 任务流程设计

### 2.1 状态机设计

任务执行采用有限状态机（FSM）管理，共 6 个状态：

| 状态 | 说明 | 触发条件 | 输出动作 |
| :---: | :--- | :--- | :--- |
| **IDLE** | 初始空闲 | 启动时 | 记录起点位姿 |
| **GO_TO_CENTER** | 前往搜索中心  | 起点记录完成 | 发布导航目标 |
| **SEARCHING** | 360° 旋转搜索 | 到达中心点 | 发布旋转速度指令 |
| **NAVIGATE_TO_BUTTER** | 导航到黄油 | 检测到黄油 | 计算目标位姿并导航 |
| **GRASPING** | 执行抓取 | 距离 < 0.3m  | 发布舵机控制指令 |
| **RETURN_HOME** | 返回起点 | 抓取完成 | 导航回起点 |

### 2.2 完整任务流程

```text
[启动]
  ↓
[记录当前位置作为起点]
  ↓
[导航到预设中心点 (center_x, center_y)]
  ↓
[原地旋转 360° 搜索黄油]
  ↓
[检测到黄油?] ──否──→ [继续旋转]
  ↓ 是
[停止旋转，计算黄油全局坐标]
  ↓
[导航到黄油位置]
  ↓
[距离 < 0.3m?] ──否──→ [继续接近]
  ↓ 是
[停止移动，发送抓取指令]
  ↓
[等待 3 秒（抓取动作执行）]
  ↓
[导航返回起点]
  ↓
[任务完成]
```

## 3. Nav2 核心组件

### 3.1 定位模块 (AMCL)

**功能**：基于粒子滤波的蒙特卡洛定位算法，融合雷达数据与里程计实现机器人在地图中的定位。

**关键参数**：

- `max_particles: 2000`：粒子数量，影响定位精度和计算量
- `laser_model_type: likelihood_field`：激光模型类型
- `update_min_d: 0.25`：移动 0.25m 触发一次更新
- `update_min_a: 0.2`：旋转 0.2rad 触发一次更新

**输出**：发布 `map` → `odom` 的 TF 变换

### 3.2 全局规划器 (NavFn Planner)

**功能**：基于 Dijkstra 算法在静态地图上规划从起点到终点的最优路径。

**特点**：

- 考虑静态障碍物和膨胀区域
- 生成平滑的全局路径
- 路径更新频率：20Hz

### 3.3 局部规划器 (DWB Controller)

**功能**：动态窗口法（Dynamic Window Approach）局部轨迹规划，实时避障。

**工作原理**：

1. 在速度空间采样多条候选轨迹（vx, vy, vθ）
2. 对每条轨迹评分（路径跟随、目标接近、障碍避让）
3. 选择得分最高的轨迹执行

**关键参数**：

- `max_vel_x: 0.15`：最大线速度 (m/s)
- `max_vel_theta: 1.0`：最大角速度 (rad/s)
- `sim_time: 1.5`：轨迹预测时间 (s)

### 3.4 代价地图 (Costmap 2D)

**功能**：构建机器人周围环境的代价地图，用于路径规划和避障。

**三层结构**：

1. **静态层 (Static Layer)**：加载 SLAM 构建的静态地图
2. **障碍层 (Obstacle Layer)**：实时雷达检测的动态障碍物
3. **膨胀层 (Inflation Layer)**：障碍物周围膨胀安全区域

**全局 vs 局部代价地图**：

- 全局代价地图：覆盖整个地图，用于全局路径规划
- 局部代价地图：3m×3m 滚动窗口，用于局部避障

## 4. 功能包结构

### 4.1 hy_nav2 功能包目录结构

```text
hy_nav2/
├── config/
│   ├── nav2_params.yaml          # Nav2 核心参数配置
│   └── map_server_params.yaml    # 地图服务器配置
├── launch/
│   ├── nav2_bringup.launch.py    # Nav2 导航栈启动
│   └── butter_mission.launch.py  # 完整任务启动
├── hy_nav2/
│   ├── __init__.py
│   └── butter_mission_node.py    # 任务调度节点
├── package.xml
└── setup.py
```

### 4.2 核心文件说明

**nav2_params.yaml**

- 包含 AMCL、控制器、规划器、代价地图等所有 Nav2 组件的参数
- 需根据机器人实际尺寸调整 `robot_radius: 0.15`
- 速度限制需与底盘实际能力匹配

**butter_mission_node.py**

- 实现状态机逻辑
- 订阅 `/detections` 话题获取目标检测结果
- 发布 `/cmd_vel` 控制机器人运动
- 调用 Nav2 的 `NavigateToPose` Action 进行导航

**nav2_bringup.launch.py**

- 启动地图服务器（加载 SLAM 地图）
- 启动 AMCL 定位节点
- 启动 Nav2 导航栈（规划器、控制器、行为服务器）

## 5. 开发流程

### 5.1 配置文件编写

**步骤 1：创建 Nav2 参数文件**

在 `config/nav2_params.yaml` 中配置：

- AMCL 定位参数（粒子数、更新阈值）
- 控制器参数（速度限制、加速度限制）
- 规划器参数（路径规划算法）
- 代价地图参数（分辨率、膨胀半径）

```{tip}
可参考 Nav2 官方示例：`/opt/ros/humble/share/nav2_bringup/params/nav2_params.yaml`
```

**步骤 2：适配机器人参数**

根据黄油机器人实际情况调整：

- `robot_radius: 0.15`（机器人半径，单位：米）
- `max_vel_x: 0.15`（最大线速度，与底盘能力匹配）
- `inflation_radius: 0.35`（障碍物膨胀半径，确保安全距离）

### 5.2 任务调度节点开发

**核心功能实现**：

1. **状态机管理**：使用 Python Enum 定义状态，在定时器回调中切换状态
2. **Action Client**：调用 Nav2 的 `NavigateToPose` Action 发送导航目标
3. **视觉融合**：订阅 `/detections` 话题，解析黄油位置信息
4. **坐标转换**：将相机坐标系下的目标位置转换为地图坐标系

**关键接口**：

- 订阅：`/detections` (目标检测结果)、`/amcl_pose` (当前位姿)
- 发布：`/cmd_vel` (速度控制)、`/joint_commands` (舵机控制)
- Action：`/navigate_to_pose` (导航目标)

### 5.3 启动文件编写

**nav2_bringup.launch.py 职责**：

- 启动 Map Server（加载 `hy_slam` 保存的地图）
- 启动 AMCL 定位节点
- 启动 Nav2 导航栈（通过 `navigation_launch.py`）
- 启动 Lifecycle Manager 管理节点生命周期

**butter_mission.launch.py 职责**：

- 包含 `nav2_bringup.launch.py`
- 启动任务调度节点 `butter_mission_node`
- 传递参数：中心点坐标、搜索速度等

## 6. 编译与运行

### 6.1 编译功能包

```bash
cd ~/hy_linux/nfs/hy_ros
colcon build --packages-select hy_nav2
source install/setup.bash
```

### 6.2 启动系统

**前置条件**：确保已完成 SLAM 建图并保存地图文件到 `install/hy_slam/share/hy_slam/map/`

```bash
# 终端 1：启动基础系统（雷达+底盘+里程计融合）
ros2 launch ldlidar_driver_ros2 ldlidar_driver.launch.py &
ros2 launch uart uart_launch.py &
ros2 launch ekf_odom ekf_odom_launch.py &
ros2 launch hy_slam laser_filter_only.launch.py

# 终端 2：启动视觉检测（摄像头+YOLOv8+推流）
ros2 launch rk_camera camera_inference_streamer.launch.py

# 终端 3：启动 Nav2 导航栈
ros2 launch hy_nav2 nav2_bringup.launch.py

# 终端 4：启动任务调度节点
ros2 launch hy_nav2 butter_mission.launch.py
```

```{tip}
可使用 `tmux` 或 `screen` 管理多个终端，或参考 `all_launch` 功能包编写统一的 launch 文件整合所有节点。
```

## 7. 调试与验证

### 7.1 检查系统状态

**验证 TF 树完整性**

```bash
# 生成 TF 树图
ros2 run tf2_tools view_frames

# 检查关键坐标变换
ros2 run tf2_ros tf2_echo map base_link
```

应包含完整链路：`map` → `odom` → `base_link` → `laser_link`

**检查话题通信**

```bash
# 查看导航相关话题
ros2 topic list | grep -E 'cmd_vel|odom|scan|map|amcl'

# 查看目标检测结果
ros2 topic echo /detections

# 查看机器人位姿
ros2 topic echo /amcl_pose
```

**检查 Action 服务**

```bash
# 查看可用 Action
ros2 action list

# 查看导航 Action 状态
ros2 action info /navigate_to_pose
```

### 7.2 常见问题排查

**问题 1：机器人不移动**

- 检查 `/cmd_vel` 话题是否有数据：`ros2 topic hz /cmd_vel`
- 检查 TF 树是否完整（特别是 `map` → `odom` 变换）
- 确认底盘串口通信正常

**问题 2：定位漂移**

- 增加 AMCL 粒子数：`max_particles: 2000 → 3000`
- 检查里程计数据质量：`ros2 topic echo /odom`
- 确认地图与实际环境一致

**问题 3：路径规划失败**

- 检查代价地图：`ros2 topic echo /global_costmap/costmap --once`
- 减小膨胀半径：`inflation_radius: 0.35 → 0.25`
- 确认目标点在可达区域内

**问题 4：搜索时未检测到黄油**

- 检查视觉检测节点是否运行：`ros2 node list | grep inference`
- 查看检测结果：`ros2 topic echo /detections`
- 调整搜索旋转速度：`search_angular_speed: 0.5 → 0.3`

### 7.3 Foxglove 可视化

启动 Foxglove Bridge 进行实时监控：

```bash
ros2 run foxglove_bridge foxglove_bridge --ros-args -p port:=8765
```

在浏览器打开 [Foxglove Studio](https://foxglove.dev/studio)，连接到 `ws://<机器人IP>:8765`

**推荐查看的面板**：

- `/map`：静态地图
- `/global_costmap/costmap`：全局代价地图
- `/local_costmap/costmap`：局部代价地图（3m×3m 滚动窗口）
- `/plan`：全局路径
- `/local_plan`：局部轨迹
- `/amcl_pose`：定位位姿
- TF 树：坐标变换关系

## 8. 参数调优建议

### 8.1 速度参数

根据实际测试调整机器人运动速度：

- `max_vel_x: 0.15`：最大线速度，过大可能导致失控
- `max_vel_theta: 1.0`：最大角速度，影响转弯灵活性
- `acc_lim_x: 0.5`：线加速度限制，避免急加速
- `acc_lim_theta: 1.5`：角加速度限制

### 8.2 目标容差

调整到达目标的精度要求：

- `xy_goal_tolerance: 0.15`：位置容差（米），过小可能无法到达
- `yaw_goal_tolerance: 0.25`：角度容差（弧度）

### 8.3 代价地图参数

- `robot_radius: 0.15`：机器人半径，需实测确定
- `inflation_radius: 0.35`：膨胀半径，确保安全距离
- `obstacle_max_range: 2.5`：障碍物检测最大距离

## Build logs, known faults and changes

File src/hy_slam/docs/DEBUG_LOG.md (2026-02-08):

# hy_slam 功能包调试日志

**项目**: 黄油机器人 ROS2 SLAM 系统
**功能包**: hy_slam
**调试日期**: 2026-01-22
**调试目标**: 实现 SLAM 建图、定位和雷达过滤三个核心功能

---

## 问题清单

###

---

**文档维护者**: Claude Code (Anthropic AI Assistant)
**最后更新**: 2026-01-20
**版本**: v1.0

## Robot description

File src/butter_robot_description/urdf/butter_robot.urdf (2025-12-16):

<?xml version="1.0" encoding="utf-8"?>
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
<robot name="黄油机器人总装.SLDASM">
  <link name="base_link">
    <inertial>
      <origin xyz="-0.00292832832758017 -1.49208294795283E-06 0.0511834353991711" rpy="0 0 0" />
      <mass value="0.447143211592946" />
      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
    </inertial>
    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
  </link>
  <link name="left_wheel_Link">
    <inertial>
      <origin xyz="0 0.0261582764619339 0" rpy="0 0 0" />
      <mass value="0.016704648971492" />
      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
    </inertial>
    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
  </link>
  <joint name="left_wheel_joint" type="continuous">
    <origin xyz="0.055 0.038192 0.021" rpy="0 0 0" />
    <parent link="base_link" />
    <child link="left_wheel_Link" />
    <axis xyz="0 1 0" />
  </joint>
  <link name="right_wheel_Link">
    <inertial>
      <origin xyz="-5.55111512312578E-17 -0.0261582764619342 1.11022302462516E-16" rpy="0 0 0" />
      <mass value="0.0167046489714922" />
      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
    </inertial>
    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
  </link>
  <joint name="right_wheel_joint" type="continuous">
    <origin xyz="-0.055 -0.038192 0.021" rpy="0 0 0" />
    <parent link="base_link" />
    <child link="right_wheel_Link" />
    <axis xyz="0 -1 0" />
  </joint>
  <link name="radar_Link">
    <inertial>
      <origin xyz="-6.26931848729528E-06 -3.11780995042032E-05 0.00198624050311713" rpy="0 0 0" />
      <mass value="0.0135497960114241" />
      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
    </inertial>
    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
  </link>
  <joint name="radar_joint" type="fixed">
    <origin xyz="0.029032 0 0.0532" rpy="0 0 0" />
    <parent link="base_link" />
    <child link="radar_Link" />
    <axis xyz="0 0 0" />
  </joint>
  <link name="spine_Link">
    <inertial>
      <origin xyz="0.00921219263683126 0.0257956453067615 0.0864977425737939" rpy="0 0 0" />
      <mass value="0.476832015741623" />
      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
    </inertial>
    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
  </link>
  <joint name="spine_joint" type="revolute">
    <origin xyz="-0.016595 -0.026 0.15501" rpy="0 0 0" />
    <parent link="base_link" />
    <child link="spine_Link" />
    <axis xyz="0 1 0" />
    <limit lower="0" upper="0" effort="0" velocity="0" />
  </joint>
  <link name="camera_Link">
    <inertial>
      <origin xyz="-0.0121170231413265 -5.16154742259689E-07 0.000244839142819697" rpy="0 0 0" />
      <mass value="0.00395486151787577" />
      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
    </inertial>
    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
  </link>
  <joint name="camera_joint" type="fixed">
    <origin xyz="0.069858 0.024995 0.11868" rpy="0 0 0" />
    <parent link="spine_Link" />
    <child link="camera_Link" />
    <axis xyz="0 0 0" />
  </joint>
  <link name="left_arm_Link">
    <inertial>
      <origin xyz="0.0295565791825624 0.0112543076706821 -0.0875821033420051" rpy="0 0 0" />
      <mass value="0.0563464968853677" />
      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
    </inertial>
    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
  </link>
  <joint name="left_arm_joint" type="revolute">
    <origin xyz="-0.00014152 0.089595 0.11868" rpy="0 0 0" />
    <parent link="spine_Link" />
    <child link="left_arm_Link" />
    <axis xyz="0 -1 0" />
    <limit lower="0" upper="0" effort="0" velocity="0" />
  </joint>
  <link name="right_arm_Link">
    <inertial>
      <origin xyz="0.0296716767832235 -0.0112543076779538 -0.0875540624679464" rpy="0 0 0" />
      <mass value="0.0563464968970425" />
      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
    </inertial>
    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
  </link>
  <joint name="right_arm_joint" type="revolute">
    <origin xyz="-0.00014152 -0.039605 0.11868" rpy="0 0 0" />
    <parent link="spine_Link" />
    <child link="right_arm_Link" />
    <axis xyz="0 -1 0" />
    <limit lower="0" upper="0" effort="0" velocity="0" />
  </joint>
</robot>

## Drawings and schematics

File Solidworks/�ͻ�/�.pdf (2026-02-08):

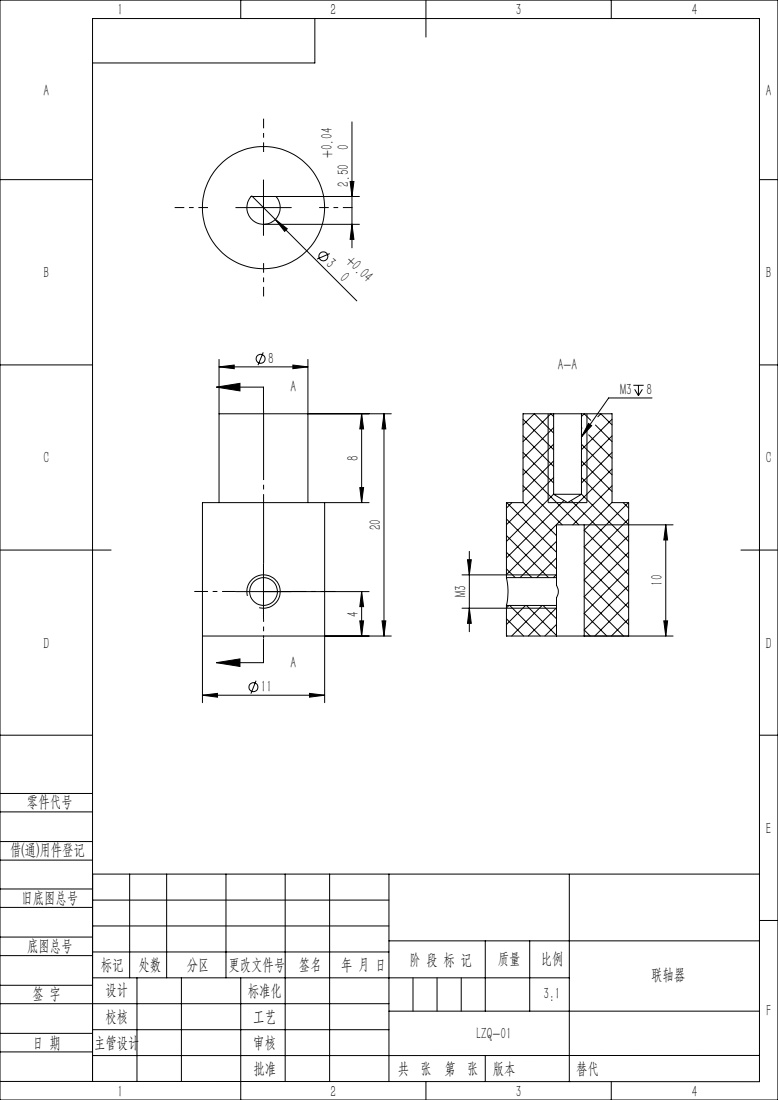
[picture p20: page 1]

阶 段 标 记 | 质量 | 比例 | 联轴器

标记 | 处数 | 分区 | 更改文件号 | 签名 | 年 月 日
设计 | | | 标准化 | | | | | | 3:1
校核 | | | 工艺
主管设计 | | | 审核

LZQ-01

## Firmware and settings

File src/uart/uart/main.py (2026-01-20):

import rclpy
from rclpy.node import Node
from sensor_msgs.msg import JointState, Joy, Imu
from nav_msgs.msg import Odometry
from std_msgs.msg import UInt16, UInt8
from pid_debug_interfaces.msg import MotorControl, MotorStatus
import serial
import threading
import time
import ctypes
import queue
import math

# 预计算常量
DEG_TO_RAD = math.pi / 180.0

# ==========================================
# 数据包结构定义 (与 C 代码保持一致)
# ==========================================

class UartUplinkPacket(ctypes.LittleEndianStructure):
    """
    @brief 上行数据包结构（设备上报给上位机）
    """
    _pack_ = 1
    _fields_ = [
        ("start_flag", ctypes.c_uint8),      # 0xAA
        ("chat_gpt_count", ctypes.c_uint16),
        
        # --- 电机与PID状态 (调试用) ---
        ("left_target_speed", ctypes.c_float),
        ("right_target_speed", ctypes.c_float),
        ("left_actual_speed", ctypes.c_float),
        ("right_actual_speed", ctypes.c_float),
        ("left_kp", ctypes.c_float),
        ("left_ki", ctypes.c_float),
        ("left_kd", ctypes.c_float),
        ("right_kp", ctypes.c_float),
        ("right_ki", ctypes.c_float),
        ("right_kd", ctypes.c_float),

        # --- 里程计与姿态 (用于SLAM/Nav/RVIZ) ---
        ("position_x", ctypes.c_float),  # m
        ("position_y", ctypes.c_float),  # m
        ("theta_wheel", ctypes.c_float), # rad
        ("linear_vel_x", ctypes.c_float), # m/s
        ("angular_vel_wheel", ctypes.c_float), # rad/s

        # --- IMU 传感器部分 ---
        ("gyro_x", ctypes.c_float),
        ("gyro_y", ctypes.c_float),
        ("gyro_z", ctypes.c_float),

        # 姿态四元数 (用于数字孪生)
        ("q_w", ctypes.c_float),
        ("q_x", ctypes.c_float),
        ("q_y", ctypes.c_float),
        ("q_z", ctypes.c_float),

        # --- 关节状态 (用于Joint State) ---
        ("servo_a_angle", ctypes.c_int16), 
        ("servo_b_angle", ctypes.c_int16),
        ("servo_c_angle", ctypes.c_int16),

        ("timestamp", ctypes.c_uint32),
        ("end_flag", ctypes.c_uint8),        # 0x55
    ]
    
    START_FLAG = 0xAA
    END_FLAG = 0x55


class UartDownlinkPacket(ctypes.LittleEndianStructure):
    """
    @brief 下行数据包结构（上位机下发给设备）
    用于下发状态标志位
    """
    _pack_ = 1
    _fields_ = [
        ("start_flag", ctypes.c_uint8),      # 0xAA
        
        ("audio_stream_flag", ctypes.c_uint8), # 音频状态: 0=无, 1=ASR结束, 2=TTS结束, 3=HTTPS下发完成
        ("left_target_speed", ctypes.c_float),  # 左电机目标速度
        ("right_target_speed", ctypes.c_float), # 右电机目标速度
        ("left_kp", ctypes.c_float),            # 左电机PID比例系数
        ("left_ki", ctypes.c_float),            # 左电机PID积分系数
        ("left_kd", ctypes.c_float),            # 左电机PID微分系数
        ("right_kp", ctypes.c_float),           # 右电机PID比例系数
        ("right_ki", ctypes.c_float),           # 右电机PID积分系数
        ("right_kd", ctypes.c_float),           # 右电机PID微分系数

        ("linear_vel", ctypes.c_float),         # 线速度 (m/s)
        ("angular_vel", ctypes.c_float),        # 角速度 (rad/s)
        ("servo_a_angle", ctypes.c_float),      # 舵机A角度 (rad)
        ("servo_b_angle", ctypes.c_float),      # 舵机B角度 (rad)
        ("servo_c_angle", ctypes.c_float),      # 舵机C角度 (rad)

        ("timestamp", ctypes.c_uint32),        # 时间戳 (ms)
        ("end_flag", ctypes.c_uint8),        # 0x66
    ]
    
    START_FLAG = 0xAA
    END_FLAG = 0x66


class UartNode(Node):
    """
    串口通讯节点（UART）
    事件驱动模式：收到 audio_stream_flag 话题更新时立即下发串口指令。
    """

    def __init__(self):
        super().__init__(
            'uart',
            allow_undeclared_parameters=False,
            automatically_declare_parameters_from_overrides=True,
        )
        
        # 1. 参数读取
        self.port = self._require_str('port')
        self.baud = self._require_int('baud')
        self.chat_topic = self._require_str('pub_chat_topic')
        self.motor_status_topic = self._require_str('pub_motor_status_topic')
        self.wheel_odom_topic = self._require_str('pub_wheel_odom_topic')
        self.imu_data_topic = self._require_str('pub_imu_data_topic')
        self.audio_status_topic = self._require_str('sub_audio_status_topic')
        self.motor_control_topic = self._require_str('sub_motor_control_topic')
        self.joy_topic = self._require_str('sub_joy_topic')

        # 2. 通信资源初始化
        self._ser = None
        self._serial_lock = threading.Lock()
        self._buf = bytearray()
        self._stop = threading.Event()
        self.send_queue = queue.Queue()
        
        # Joy Control State
        self.joy_servo_a = 0.0
        self.joy_servo_b = 0.0
        self.joy_servo_c = 0.0
        self.last_buttons = []
        self._buttons_len = 0  # 缓存按钮数组长度
        
        # 3. ROS 接口
        # [Pub] 上行
        self.pub_chat = self.create_publisher(UInt16, self.chat_topic, 10)
        self.pub_motor_status = self.create_publisher(MotorStatus, self.motor_status_topic, 10)
        self.pub_joint_state = self.create_publisher(JointState, 'joint_states', 10)

        self.pub_odom = self.create_publisher(Odometry, self.wheel_odom_topic, 10)
        self.pub_imu = self.create_publisher(Imu, self.imu_data_topic, 10)

        # 预分配消息对象 (避免回调中频繁创建)
        self._downlink_packet = UartDownlinkPacket()
        self._joint_msg = JointState()
        self._joint_msg.name = ['right_arm_joint', 'left_arm_joint', 'spine_joint']
        self._joint_msg.position = [0.0, 0.0, 0.0]
        self._odom_msg = Odometry()
        self._odom_msg.header.frame_id = "odom"
        self._odom_msg.child_frame_id = "base_link"
        self._imu_msg = Imu()
        self._imu_msg.header.frame_id = "base_link"
        self._motor_status_msg = MotorStatus()
        self._chat_msg = UInt16()  # 预分配 chat 消息

        # [Sub] 下行
        self.sub_audio_status = self.create_subscription(
            UInt8, self.audio_status_topic, self._on_audio_status, 10)
        self.sub_motor_control = self.create_subscription(
            MotorControl, self.motor_control_topic, self._on_motor_control, 10)
        self.sub_joy = self.create_subscription(
            Joy, self.joy_topic, self._on_joy, 10)
        
        # 4. 启动线程
        self._open()
        self._read_thread = threading.Thread(target=self._run_read, daemon=True)
        self._read_thread.start()
        self._write_thread = threading.Thread(target=self._run_write, daemon=True)
        self._write_thread.start()
        
        self.get_logger().info(f'UART 节点启动。事件驱动模式。端口: {self.port}')

    def _on_audio_status(self, msg: UInt8):
        """
        ROS 回调：收到音频状态更新，立即组装下行包发送。
        """
        flag = msg.data
        # 复用预分配的下行包对象
        packet = UartDownlinkPacket()
        packet.start_flag = UartDownlinkPacket.START_FLAG
        packet.audio_stream_flag = flag
        packet.timestamp = int(time.time() * 1000) & 0xFFFFFFFF
        packet.end_flag = UartDownlinkPacket.END_FLAG

        self.send_queue.put(packet)

    def _on_joy(self, msg: Joy):
        """
        ROS 回调：收到手柄数据，解析并控制
        """
        # 1. 解析 Axes (前4个)
        linear = 0.0
        angular = 0.0
        if len(msg.axes) >= 4:
            linear = msg.axes[1] * 0.11  # Max 0.11 m/s
            angular = msg.axes[3] * 1.76 # Max 1.76 rad/s

        # 2. 解析 Buttons (前6个) - 优化：避免每次创建新列表
        buttons = msg.buttons
        btn_len = len(buttons)
        if self._buttons_len != btn_len:
            self.last_buttons = [0] * btn_len
            self._buttons_len = btn_len

        # 内联检查按钮按下（避免函数调用开销）
        last = self.last_buttons
        if btn_len > 0 and buttons[0] == 1 and last[0] == 0:
            self.joy_servo_a += 5.0
        if btn_len > 1 and buttons[1] == 1 and last[1] == 0:
            self.joy_servo_a -= 5.0
        if btn_len > 2 and buttons[2] == 1 and last[2] == 0:
            self.joy_servo_b += 5.0
        if btn_len > 3 and buttons[3] == 1 and last[3] == 0:
            self.joy_servo_b -= 5.0
        if btn_len > 4 and buttons[4] == 1 and last[4] == 0:
            self.joy_servo_c += 5.0
        if btn_len > 5 and buttons[5] == 1 and last[5] == 0:
            self.joy_servo_c -= 5.0

        # 原地更新而非创建新列表
        for i in range(btn_len):
            last[i] = buttons[i]

        # 3. 发送下行包
        packet = UartDownlinkPacket()
        packet.start_flag = UartDownlinkPacket.START_FLAG
        packet.audio_stream_flag = 0
        
        packet.linear_vel = float(linear)
        packet.angular_vel = float(angular)
        
        packet.servo_a_angle = float(self.joy_servo_a)
        packet.servo_b_angle = float(self.joy_servo_b)
        packet.servo_c_angle = float(self.joy_servo_c)
        
        packet.timestamp = int(time.time() * 1000) & 0xFFFFFFFF
        packet.end_flag = UartDownlinkPacket.END_FLAG
        
        # DEBUG: 打印调试信息
        self.get_logger().debug(
            f"[Joy Debug] Linear={packet.linear_vel:.2f}, Angular={packet.angular_vel:.2f}, "
            f"Servo A={packet.servo_a_angle:.2f}, Servo B={packet.servo_b_angle:.2f}, Servo C={packet.servo_c_angle:.2f}"
        )
        
        # 暂时注释掉串口下发，等待调试确认
        self.send_queue.put(packet)

    def _on_motor_control(self, msg: MotorControl):
        """
        ROS 回调：收到电机控制指令，组装下行包发送。
        """
        packet = UartDownlinkPacket()
        packet.start_flag = UartDownlinkPacket.START_FLAG
        packet.audio_stream_flag = 0 # 提供默认值即可
        packet.left_target_speed = msg.left_target_speed
        packet.right_target_speed = msg.right_target_speed
        packet.left_kp = msg.left_kp
        packet.left_ki = msg.left_ki
        packet.left_kd = msg.left_kd
        packet.right_kp = msg.right_kp
        packet.right_ki = msg.right_ki
        packet.right_kd = msg.right_kd
        
        packet.linear_vel = msg.linear_vel
        packet.angular_vel = msg.angular_vel
        packet.servo_a_angle = msg.servo_a_angle
        packet.servo_b_angle = msg.servo_b_angle
        packet.servo_c_angle = msg.servo_c_angle

        packet.timestamp = int(time.time() * 1000) & 0xFFFFFFFF
        packet.end_flag = UartDownlinkPacket.END_FLAG
        
        self.send_queue.put(packet)
        
        # 打印发送的电机控制指令
        self.get_logger().info(f"发送电机控制指令: "
                               f"左目标速度={packet.left_target_speed:.2f}, "
                               f"右目标速度={packet.right_target_speed:.2f}, "
                               f"左PID={packet.left_kp:.2f},{packet.left_ki:.2f},{packet.left_kd:.2f}, "
                               f"右PID={packet.right_kp:.2f},{packet.right_ki:.2f},{packet.right_kd:.2f}, "
                               f"线速度={packet.linear_vel:.2f}, 角速度={packet.angular_vel:.2f}, "
                               f"舵机={packet.servo_a_angle:.2f},{packet.servo_b_angle:.2f},{packet.servo_c_angle:.2f}")

    def _open(self):
        with self._serial_lock:
            try:
                self._ser = serial.Serial(
                    self.port,
                    self.baud,
                    bytesize=serial.EIGHTBITS,
                    parity=serial.PARITY_NONE,
                    stopbits=serial.STOPBITS_ONE,
                    timeout=0.01, # 读超时
                    write_timeout=1,
                )
                self.get_logger().info(f'已打开串口 {self.port}，波特率 {self.baud}')
            except Exception as e:
                self.get_logger().error(f'打开串口失败：{e}')
                self._ser = None

    def _run_write(self):
        """写线程：从队列获取数据包并写入串口"""
        while not self._stop.is_set():
            try:
                # 阻塞等待，超时方便响应停止信号
                packet = self.send_queue.get(timeout=0.5)
                
                if self._ser and self._ser.is_open:
                    data = bytes(packet)
                    with self._serial_lock:
                        self._ser.write(data)
                    self.get_logger().debug(f"发送下行数据: {[hex(b) for b in data]}")
                else:
                    self.get_logger().warning("串口未打开，丢弃发送数据")
                
                self.send_queue.task_done()
            except queue.Empty:
                continue
            except Exception as e:
                self.get_logger().error(f"写串口异常: {e}")

    def _run_read(self):
        """读线程：循环读取并解析"""
        while not self._stop.is_set():
            if self._ser is None or not self._ser.is_open:
                time.sleep(1.0)
                self._open()
                continue
                
            try:
                data = b''
                if self._ser.in_waiting:
                    with self._serial_lock:
                        data = self._ser.read(self._ser.in_waiting)
                
                if data:
                    self._buf.extend(data)
                    self._parse()
                else:
                    time.sleep(0.005)
            except Exception as e:
                self.get_logger().error(f'读串口异常: {e}')
                time.sleep(1.0)

    def _parse(self):
        """解析上行数据包 (UplinkPacket)"""
        b = self._buf
        packet_size = ctypes.sizeof(UartUplinkPacket)
        
        while len(b) >= packet_size:
            # 1. 寻找起始标志
            try:
                idx = b.index(UartUplinkPacket.START_FLAG)
            except ValueError:
                b.clear()
                break
                
            if idx > 0:
                del b[:idx] # 丢弃头部噪声
                continue # 重新检查长度
            
            # 此时 b[0] == START_FLAG
            if len(b) < packet_size:
                break # 数据不够完整包
            
            # 2. 检查结束标志
            if b[packet_size - 1] != UartUplinkPacket.END_FLAG:
                del b[0]
                continue
                
            # 3. 解析数据
            try:
                # 直接从 buffer 解析，避免额外拷贝
                packet = UartUplinkPacket.from_buffer_copy(b[:packet_size])

                # 获取当前时间戳，用于同步
                current_time = self.get_clock().now().to_msg()

                # 发布话题 - 使用预分配对象
                self._chat_msg.data = packet.chat_gpt_count
                self.pub_chat.publish(self._chat_msg)

                # 1. 发布 MotorStatus (电机状态，用于PID调试) - 使用预分配对象
                status_msg = self._motor_status_msg
                status_msg.left_target_speed = packet.left_target_speed
                status_msg.right_target_speed = packet.right_target_speed
                status_msg.left_actual_speed = packet.left_actual_speed
                status_msg.right_actual_speed = packet.right_actual_speed
                status_msg.left_kp = packet.left_kp
                status_msg.left_ki = packet.left_ki
                status_msg.left_kd = packet.left_kd
                status_msg.right_kp = packet.right_kp
                status_msg.right_ki = packet.right_ki
                status_msg.right_kd = packet.right_kd
                self.pub_motor_status.publish(status_msg)

                # 2. 发布 JointState (关节状态) - 使用预分配对象
                joint_msg = self._joint_msg
                joint_msg.header.stamp = current_time
                # 使用预计算常量 DEG_TO_RAD
                joint_msg.position[0] = float(packet.servo_a_angle) * DEG_TO_RAD
                joint_msg.position[1] = float(packet.servo_b_angle) * DEG_TO_RAD
                joint_msg.position[2] = float(packet.servo_c_angle) * DEG_TO_RAD
                self.pub_joint_state.publish(joint_msg)

                # 3. 发布 Odometry - 使用预分配对象
                odom_msg = self._odom_msg
                odom_msg.header.stamp = current_time

                # 位置 (m)
                odom_msg.pose.pose.position.x = float(packet.position_x)
                odom_msg.pose.pose.position.y = float(packet.position_y)
                odom_msg.pose.pose.position.z = 0.0

                # 姿态 (Theta -> Quaternion)
                half_theta = float(packet.theta_wheel) * 0.5
                odom_msg.pose.pose.orientation.z = math.sin(half_theta)
                odom_msg.pose.pose.orientation.w = math.cos(half_theta)

                # 速度
                odom_msg.twist.twist.linear.x = float(packet.linear_vel_x)
                odom_msg.twist.twist.angular.z = float(packet.angular_vel_wheel)

                self.pub_odom.publish(odom_msg)

                # 4. 发布 IMU - 使用预分配对象
                imu_msg = self._imu_msg
                imu_msg.header.stamp = current_time

                # 角速度 (rad/s)
                imu_msg.angular_velocity.x = float(packet.gyro_x)
                imu_msg.angular_velocity.y = float(packet.gyro_y)
                imu_msg.angular_velocity.z = -float(packet.gyro_z)  # 取反适配 ROS 坐标系

                # 姿态 (四元数) - 取反 z 适配 ROS ENU 坐标系
                imu_msg.orientation.w = float(packet.q_w)
                imu_msg.orientation.x = float(packet.q_x)
                imu_msg.orientation.y = float(packet.q_y)
                imu_msg.orientation.z = -float(packet.q_z)

                self.get_logger().debug(f"解析上行: gyro_x={packet.gyro_x:.2f}, "
                                       f"gyro_y={packet.gyro_y:.2f}, "
                                       f"gyro_z={packet.gyro_z:.2f}, "
                                       f"q_w={packet.q_w:.2f}, "
                                       f"q_x={packet.q_x:.2f}, "
                                       f"q_y={packet.q_y:.2f}, "
                                       f"q_z={packet.q_z:.2f}, "
                                       f"时间ms={packet.timestamp:.2f}")

                self.pub_imu.publish(imu_msg)

                self.get_logger().debug(
                    f"解析上行: Count={packet.chat_gpt_count}, TS={packet.timestamp}"
                )
                self.get_logger().debug(f"解析上行: 左目标速度={packet.left_target_speed:.2f}, "
                                       f"右目标速度={packet.right_target_speed:.2f}, "
                                       f"左实际速度={packet.left_actual_speed:.2f}, "
                                       f"右实际速度={packet.right_actual_speed:.2f}, "
                                       f"左PID={packet.left_kp:.2f},{packet.left_ki:.2f},{packet.left_kd:.2f}, "
                                       f"右PID={packet.right_kp:.2f},{packet.right_ki:.2f},{packet.right_kd:.2f}")
    
                
                # 4. 移除已解析的数据
                del b[:packet_size]
                
            except Exception as e:
                self.get_logger().error(f"解析包内容异常: {e}")
                del b[0] # 防死循环

    def destroy_node(self):
        self._stop.set()
        if self._ser:
            self._ser.close()
        return super().destroy_node()

    def _require_str(self, name: str) -> str:
        p = self.get_parameter(name)
        v = p.value
        if isinstance(v, str) and len(v) > 0:
            return v
        raise RuntimeError(f"缺少必需字符串参数: {name}")

    def _require_int(self, name: str) -> int:
        p = self.get_parameter(name)
        v = p.value
        if isinstance(v, int):
            return v
        raise RuntimeError(f"缺少必需整数参数: {name}")


def main(args=None):
    rclpy.init(args=args)
    node = UartNode()
    try:
        rclpy.spin(node)
    except KeyboardInterrupt:
        pass
    finally:
        node.destroy_node()
        rclpy.shutdown()

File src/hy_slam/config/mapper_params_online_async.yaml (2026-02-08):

# 在线异步建图参数配置文件 (Online Async Mapping)
# 用途：用于实时构建地图。
# 特点：异步处理，适合计算资源有限的嵌入式平台（如 RK3588），即使建图处理滞后也不会阻塞传感器数据的采集。

slam_toolbox:
  ros__parameters:
    # ========================================================
    # 求解器插件配置 (Solver Plugin Parameters)
    # ========================================================
    solver_plugin: solver_plugins::CeresSolver
    ceres_linear_solver: SPARSE_NORMAL_CHOLESKY
    ceres_preconditioner: SCHUR_JACOBI
    ceres_trust_strategy: LEVENBERG_MARQUARDT
    ceres_dogleg_type: TRADITIONAL_DOGLEG
    ceres_loss_function: None
    ceres_loss_funciton : None
    ceres_loss_funciton : None
    ceres_loss_funciton : None
    ceres_loss_funciton : None``````````````````````````````````````` 


    # ========================================================
    # ROS 坐标系与话题配置 (Frames & Topics)
    # ========================================================
    odom_frame: odom # 里程计坐标系
    map_frame: map # 地图坐标系
    base_frame: base_link # 机器人基座坐标系
    scan_topic: /scan # 订阅经过滤波的雷达话题（laser_filter配置了keep_point_count保持点数恒定）
    mode: mapping # 核心模式设置: 'mapping' (建图)

    # ========================================================
    # 建图核心参数 (Mapping)
    # ========================================================
    debug_logging: false
    throttle_scans: 1 # 扫描处理频率控制 (1=全处理)
    transform_publish_period: 0.02 # TF 发布周期 (0.02s = 50Hz)，提高频率确保实时性
    map_update_interval: 1.0 # 地图更新间隔 (秒)，从5.0降到1.0，foxglove实时可见
    resolution: 0.05 # 地图分辨率 (米/像素)，越小越精细但消耗内存
    max_laser_range: 12.0 # 雷达最大有效距离 (根据硬件修改，乐动ld06为12m)
    minimum_time_interval: 0.5 # 两次扫描匹配更新的最小时间间隔
    transform_timeout: 1.0 # 🔧 关键修复：从0.2增加到1.0秒，解决静态TF时间戳问题
    tf_buffer_duration: 30.
    stack_size_to_use: 40000000 # 增加程序栈大小以支持大型地图的序列化

    # ========================================================
    # 扫描匹配参数 (Scan Matching)
    # 决定了如何将新的一帧雷达数据拼接到现有地图上
    # ========================================================
    use_scan_matching: true
    use_scan_barycenter: true
    # 针对低速机器人优化 (Max v=0.11m/s, w=1.76rad/s)
    # 降低最小更新距离/角度，保证低速移动时地图也能及时更新
    minimum_travel_distance: 0.1 # 0.1m (约1秒移动的距离)
    minimum_travel_heading: 0.2 # 0.2rad (约11.5度)
    scan_buffer_size: 10
    scan_buffer_maximum_scan_distance: 10.0
    link_match_minimum_response_fine: 0.1
    link_scan_maximum_distance: 1.5

    # ========================================================
    # 回环检测参数 (Loop Closure)
    # 检测机器人是否回到之前的位置，用于消除累计误差 (闭环)
    # ========================================================
    loop_search_maximum_distance: 3.0 # 回环搜索的最大距离半径
    do_loop_closing: true # 启用回环检测 (强烈建议开启)
    loop_match_minimum_chain_size: 10
    loop_match_maximum_variance_coarse: 3.0
    loop_match_minimum_response_coarse: 0.35
    loop_match_minimum_response_fine: 0.45

    # ========================================================
    # 相关性搜索参数 (Correlation Parameters)
    # ========================================================
    correlation_search_space_dimension: 0.5
    correlation_search_space_resolution: 0.01
    correlation_search_space_smear_deviation: 0.1

    # Loop Closure Parameters
    loop_search_space_dimension: 8.0
    loop_search_space_resolution: 0.05
    loop_search_space_smear_deviation: 0.03

    # ========================================================
    # 扫描匹配器罚分参数 (Scan Matcher Penalties)
    # ========================================================
    distance_variance_penalty: 0.5
    angle_variance_penalty: 1.0

    fine_search_angle_offset: 0.00349
    coarse_search_angle_offset: 0.349
    coarse_angle_resolution: 0.0349
    minimum_angle_penalty: 0.9
    minimum_distance_penalty: 0.5
    use_response_expansion: true

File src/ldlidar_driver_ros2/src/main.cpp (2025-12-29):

/**
 * @file main.cpp
 * @author LDRobot (marketing1@ldrobot.com)
 * @brief  main process App
 *         This code is only applicable to LDROBOT LiDAR LD06 products 
 * sold by Shenzhen LDROBOT Co., LTD    
 * @version 0.1
 * @date 2021-10-28
 *
 * @copyright Copyright (c) 2021  SHENZHEN LDROBOT CO., LTD. All rights
 * reserved.
 * Licensed under the MIT License (the "License");
 * you may not use this file except in compliance with the License.
 * You may obtain a copy of the License in the file LICENSE
 * Unless required by applicable law or agreed to in writing, software
 * distributed under the License is distributed on an "AS IS" BASIS,
 * WITHOUT WARRANTIES OR CONDITIONS OF ANY KIND, either express or implied.
 * See the License for the specific language governing permissions and
 * limitations under the License.
 */

#include <rclcpp/rclcpp.hpp>
#include <stdio.h>

#include <iostream>
#include <string>

#include "cmd_interface_linux.h"
#include "lipkg.h"

int main(int argc, char **argv) {
  rclcpp::init(argc, argv);

  // create a ROS2 Node
  auto node = std::make_shared<rclcpp::Node>("ldlidar_published"); 

  std::string product_name;
	std::string topic_name;
	std::string port_name;
	std::string frame_id;
  bool laser_scan_dir = true;
  bool enable_angle_crop_func = false;
  double angle_crop_min = 0.0;
  double angle_crop_max = 0.0;
  double angle_offset = 0.0;
  
  // declare ros2 param
  node->declare_parameter<std::string>("product_name", product_name);
  node->declare_parameter<std::string>("topic_name", topic_name);
  node->declare_parameter<std::string>("port_name", port_name);
  node->declare_parameter<std::string>("frame_id", frame_id);
  node->declare_parameter<bool>("laser_scan_dir", laser_scan_dir);
  node->declare_parameter<bool>("enable_angle_crop_func", enable_angle_crop_func);
  node->declare_parameter<double>("angle_crop_min", angle_crop_min);
  node->declare_parameter<double>("angle_crop_max", angle_crop_max);
  node->declare_parameter<double>("angle_offset", angle_offset);
 
  // get ros2 param
  node->get_parameter("product_name", product_name);
  node->get_parameter("topic_name", topic_name);
  node->get_parameter("port_name", port_name);
  node->get_parameter("frame_id", frame_id);
  node->get_parameter("laser_scan_dir", laser_scan_dir);
  node->get_parameter("enable_angle_crop_func", enable_angle_crop_func);
  node->get_parameter("angle_crop_min", angle_crop_min);
  node->get_parameter("angle_crop_max", angle_crop_max);
  node->get_parameter("angle_offset", angle_offset);
 
  RCLCPP_INFO(node->get_logger(), " [ldrobot] SDK Pack Version is v2.2.10");
  RCLCPP_INFO(node->get_logger(), " [ldrobot] <product_name>: %s ,<topic_name>: %s ,<port_name>: %s ,<frame_id>: %s", 
              product_name.c_str(), topic_name.c_str(), port_name.c_str(), frame_id.c_str());

  RCLCPP_INFO(node->get_logger(), "[ldrobot] <laser_scan_dir>: %s,<enable_angle_crop_func>: %s,<angle_crop_min>: %f,<angle_crop_max>: %f,<angle_offset>: %f",
   (laser_scan_dir?"Counterclockwise":"Clockwise"), (enable_angle_crop_func?"true":"false"), angle_crop_min, angle_crop_max, angle_offset);

  LiPkg *lidar = new LiPkg(frame_id, laser_scan_dir, enable_angle_crop_func, angle_crop_min, angle_crop_max, angle_offset);
  CmdInterfaceLinux cmd_port;

  if (port_name.empty()) {
    RCLCPP_ERROR(node->get_logger(), " [ldrobot] Can't find %s device.", product_name.c_str());
    exit(EXIT_FAILURE);
  }else {
    RCLCPP_INFO(node->get_logger(), " [ldrobot] Found %s device.", product_name.c_str());
  }

  cmd_port.SetReadCallback([&lidar](const char *byte, size_t len) {
    if (lidar->Parse((uint8_t *)byte, len)) {
      lidar->AssemblePacket();
    }
  });

  if (cmd_port.Open(port_name)) {
    RCLCPP_INFO(node->get_logger(), " [ldrobot] open %s device %s success!", product_name.c_str(), port_name.c_str());
  }else {
    RCLCPP_ERROR(node->get_logger(), " [ldrobot] open %s device %s fail!", product_name.c_str(), port_name.c_str());
    exit(EXIT_FAILURE);
  }

  // create ldlidar data topic and publisher
  rclcpp::Publisher<sensor_msgs::msg::LaserScan>::SharedPtr publisher;
  publisher = node->create_publisher<sensor_msgs::msg::LaserScan>(topic_name, 10);
  
  rclcpp::WallRate r(10); //10hz
  while (rclcpp::ok()) {
    if (lidar->IsFrameReady()) {
      lidar->ResetFrameReady();
      // publish ldlidar frame data topic message
      publisher->publish(lidar->GetLaserScan());
      
#if 0 
			sensor_msgs::msg::LaserScan data = lidar->GetLaserScan();
			unsigned int lens = (data.angle_max - data.angle_min) / data.angle_increment;  
			std::cout << "[ldrobot] current_speed: " << lidar->GetSpeed() << " " 
			          << "len: " << lens << " "
					  << "angle_min: " << RADIAN_TO_ANGLED(data.angle_min) << " "
					  << "angle_max: " << RADIAN_TO_ANGLED(data.angle_max) << std::endl; 
			std::cout << "----------------------------" << std::endl;
			for (unsigned int i = 0; i < lens; i++)
			{
				std::cout << "[ldrobot] range: " <<  data.ranges[i] << " " 
						  << "intensites: " <<  data.intensities[i] << std::endl;
			}
			std::cout << "----------------------------" << std::endl;
#endif
    }
    r.sleep();
  }

  RCLCPP_INFO(node->get_logger(), "this node of ldlidar_published is end");
  rclcpp::shutdown();

  return 0;
}

/********************* (C) COPYRIGHT SHENZHEN LDROBOT CO., LTD *******END OF
 * FILE ********/

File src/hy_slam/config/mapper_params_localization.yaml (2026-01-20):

# 定位模式参数配置文件 (Localization Mode)
# 用途：在已有地图上进行纯定位（类似 AMCL），不进行建图更新。
# 适用于：导航阶段，加载已保存的 .posegraph 或 .map 地图。

slam_toolbox:
  ros__parameters:
    # ========================================================
    # 求解器插件配置 (Solver Plugin Parameters)
    # ========================================================
    # 推荐使用 CeresSolver，它是 Google 开发的高性能非线性最小二乘解算库
    solver_plugin: solver_plugins::CeresSolver
    ceres_linear_solver: SPARSE_NORMAL_CHOLESKY # 稀疏矩阵求解器，适合 SLAM
    ceres_preconditioner: SCHUR_JACOBI
    ceres_trust_strategy: LEVENBERG_MARQUARDT # 优化策略
    ceres_dogleg_type: TRADITIONAL_DOGLEG
    ceres_loss_function: None

    # ========================================================
    # ROS 坐标系与话题配置 (Frames & Topics)
    # ========================================================
    odom_frame: odom # 里程计坐标系
    map_frame: map # 地图坐标系
    base_frame: base_link # 机器人基座坐标系
    scan_topic: /scan_filtered # 订阅的雷达话题 (使用经过滤波的话题)
    mode: localization # 核心模式设置: 'localization' (纯定位) 或 'mapping' (建图)

    # ========================================================
    # 定位特定参数 (Localization Specific)
    # ========================================================
    map_file_name: "" # 地图文件路径 (通常在 launch 文件中通过命令行参数传入，此处留空)
    map_start_pose: [0.0, 0.0, 0.0] # 初始位姿估计 [x, y, theta]，用于初始化定位
    map_start_at_dock: true # 如果为 true，忽略 map_start_pose，假设机器人从原点(充电桩)启动

    # ========================================================
    # 建图/处理核心参数 (Mapping/Processing)
    # ========================================================
    debug_logging: false # 是否开启调试日志
    throttle_scans: 1 # 处理帧率控制 (1 = 处理每一帧，2 = 每隔一帧处理一次)
    transform_publish_period: 0.05 # 地图到里程计 TF 发布周期 (秒)，0.05s = 20Hz，针对嵌入式平台优化
    map_update_interval: 5.0 # 地图更新间隔 (秒)，定位模式下影响可视化更新
    resolution: 0.05 # 地图分辨率 (米/像素)
    max_laser_range: 12.0 # 雷达最大有效距离 (与建图配置保持一致，乐动ld06为12m)
    minimum_time_interval: 0.5 # 最小处理时间间隔
    transform_timeout: 0.2 # TF 变换超时时间
    tf_buffer_duration: 30. # TF 缓存时长
    stack_size_to_use: 40000000 # 序列化大地图所需的栈大小 (字节)

    # ========================================================
    # 扫描匹配参数 (Scan Matching)
    # ========================================================
    use_scan_matching: true # 是否启用扫描匹配 (必须为 true)
    use_scan_barycenter: true # 使用扫描重心进行距离计算
    # 针对低速机器人优化 (Max v=0.11m/s, w=1.76rad/s)
    # 降低最小更新距离/角度，避免低速时定位更新停滞
    minimum_travel_distance: 0.1 # 0.1m (约1秒移动的距离)
    minimum_travel_heading: 0.2 # 0.2rad (约11.5度)
    scan_buffer_size: 10 # 扫描缓冲区大小
    scan_buffer_maximum_scan_distance: 10.0 # 缓冲区最大扫描距离
    link_match_minimum_response_fine: 0.1
    link_scan_maximum_distance: 1.5

    # ========================================================
    # 回环检测参数 (Loop Closure)
    # 定位模式下，回环检测用于重定位和修正位姿
    # ========================================================
    loop_search_maximum_distance: 3.0
    do_loop_closing: true # 启用回环检测
    loop_match_minimum_chain_size: 10
    loop_match_maximum_variance_coarse: 3.0
    loop_match_minimum_response_coarse: 0.35
    loop_match_minimum_response_fine: 0.45

    # ========================================================
    # 相关性搜索参数 (Correlation Parameters)
    # 影响扫描匹配的精度和范围
    # ========================================================
    correlation_search_space_dimension: 0.5
    correlation_search_space_resolution: 0.01
    correlation_search_space_smear_deviation: 0.1

    # 回环搜索相关性参数
    loop_search_space_dimension: 8.0
    loop_search_space_resolution: 0.05
    loop_search_space_smear_deviation: 0.03

    # ========================================================
    # 扫描匹配器罚分参数 (Scan Matcher Penalties)
    # ========================================================
    distance_variance_penalty: 0.5
    angle_variance_penalty: 1.0
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

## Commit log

2025-12-06 初始提交：导入all_launch包、测试与配置
2025-12-06 基础框架搭建完成
2025-12-06 串口数据解析与发布话题话题成功
2025-12-07 新增文档说明
2025-12-10 语音流终端测试成功
2025-12-12 [音频流]大脑侧：编写ASR节点并测试通过
2025-12-12 新增audio_rkllm的c++功能包，launch通过
2025-12-12 添加librkllmrt.so库文件链接，编译测试通过
2025-12-12 rkllm功能包支持opencv库调用摄像头获取图像
2025-12-13 实现LLM文本推理和流式输入输出
2025-12-13 新增tts_python功能包
2025-12-13 tts功能包测试完成
2025-12-14 更新串口以及下行数据包；解决播放卡顿问题
2025-12-15 feat(uart): 添加电机控制和状态接口 实现电机控制指令的下行传输和状态反馈的上行解析；添加pid_debug_interfaces包定义消息类型；更新uart节点以支持电机相关话题
2025-12-15 feat(keyboard_control): 新增键盘控制节点及相关启动脚本;添加键盘控制ROS2节点，支持通过WASD等按键控制机器人运动
2025-12-16 feat(butter_robot): 添加黄油机器人URDF模型及启动文件；all_launch中并添加foxglove_bridge支持
    [base_link.STL, butter_robot.urdf, camera_Link.STL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]
2025-12-16 feat(uart): 添加关节状态和TF变换发布功能;添加sphinx自动构建脚本
2025-12-17 docs: 构文档目录结构；新增图片采集工具脚本，支持自动编号保存
2025-12-20 docs(文档): 更新产品介绍和开发指南，添加参考链接
2025-12-20 docs: 更新文档内容和构建脚本
2025-12-20 feat(rk_camera): 添加基于GStreamer的RK3588相机节点实现
    实现RK3588相机节点，支持通过GStreamer采集摄像头数据并发布为ROS2图像话题。包含完整的启动文件、参数配置和硬件加速支持。
    主要功能：
    - 使用v4l2src采集摄像头数据
    - 支持NV12格式输出
    - 可配置分辨率、帧率等参数
    - 实现零拷贝数据传输
    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
2025-12-21 feat(rk_inference): 新增Rockchip NPU推理节点及相关配置；添加rk_inference包实现基于RGA和RKNN的硬件加速推理功能
2025-12-21 feat(rk_streamer): 新增基于GStreamer的RTSP流媒体节点 实现RK3588平台的RTSP流媒体功能，包含以下主要组件： - 支持NV12格式图像直接通过GStreamer管道推流 - 可配置分辨率、帧率和RTSP输出地址 - 集成到视觉处理管道中，支持零拷贝通信 - 添加启动文件和package.xml依赖配置
2025-12-21 feat(rk_inference): 实现基于RKNN的YOLOv8目标检测功能 - 添加RKNN模型加载与初始化逻辑 - 实现RGA硬件加速的图像预处理 - 完成NPU推理及后处理流程 - 支持NV12格式的零拷贝数据传输 - 添加目标检测结果可视化功能
2025-12-21 feat(camera): 添加180度旋转功能并集成RGA硬件加速 添加摄像头180度旋转功能，通过Rockchip RGA硬件加速实现高效图像旋转 在CMakeLists中添加RGA库的查找和链接 更新launch文件以支持旋转参数配置
2025-12-22 feat(rk_streamer): 实现基于GStreamer的硬件加速RTSP推流功能 重构推流模块，使用GStreamer原生API替代OpenCV VideoWriter - 添加GStreamer依赖和硬件编码支持 - 实现GLib主循环处理RTSP网络事件 - 优化时间戳处理和缓冲区管理 - 更新文档包含完整的安装和配置指南 - 调整launch文件参数匹配新推流管道
2025-12-22 fix(rk_inference): 添加内存对齐缓冲解决RGA绘图问题并优化边界检查 - 添加aligned_buf_用于处理ROS消息内存未对齐导致的RGA绘图失败 - 实现CPU回退方案nv12_draw_rect当RGA不可用时 - 严格限制检测框坐标在图像范围内 - 更新RTSP推流配置和文档说明
2025-12-29 feat: 新增SLAM功能包及雷达驱动支持
    - 添加hy_slam功能包，包含在线建图、定位和雷达数据裁剪功能
    - 集成ldlidar_driver_ros2雷达驱动，支持LD06雷达设备
    - 新增激光雷达数据过滤配置，解决机器人后方遮挡问题
    - 实现地图保存脚本，支持通过服务调用保存SLAM生成的地图
    - 更新音频TTS功能，增加机器人音色支持和音色管理功能
    - 添加文档说明，详细描述SLAM部署和配置流程
2025-12-29 feat(audio_rkllm): 添加强制英文输出选项
    为音频RKLLM模块添加强制英文输出功能，通过配置参数控制语言输出
    同时更新.gitignore文件，取消注释相关音频节点启动配置，并调整TTS音色设置
2025-12-29 feat(uart): 添加手柄控制支持并简化启动配置 - 在uart节点中添加对sensor_msgs/Joy消息的支持，实现手柄控制 - 修改all_launch配置，移除音频和视觉相关节点以简化启动 - 更新package.xml依赖项，添加std_msgs和sensor_msgs - 调整构建脚本以包含butter_robot_description和all_launch包
2025-12-29 feat(ldlidar): 添加雷达角度偏移参数以矫正安装方向
    refactor(slam): 优化配置文件注释和参数说明
    docs: 更新开发文档并添加雷达数据可视化示例
    fix(gitignore): 修正文件路径错误
    style: 清理无用代码注释
    build: 添加一键调试脚本
    [main.cpp, mapper_params_localization.yaml, mapper_params_online_async.yaml]
2025-12-30 feat(odom): 添加EKF里程计融合功能并更新相关配置
    新增ekf_odom功能包实现轮式里程计与IMU数据融合
    更新uart节点发布wheel_odom和imu_data话题
    修改键盘控制节点速度单位为m/s和rad/s
    添加robot_localization依赖并更新文档说明
2025-12-30 feat(slam): 优化SLAM配置并添加雷达数据过滤
    - 调整SLAM参数以适应低速机器人，降低最小更新距离/角度
    - 添加雷达数据过滤配置，滤除车身遮挡区域
    - 更新启动脚本以包含ekf_odom包
    - 修改URDF使雷达和相机关节可旋转
    - 更新保存地图脚本以使用相对路径
    - 在uart节点中添加雷达和相机关节状态
    [butter_robot.urdf]
2026-01-20 feat: 启用音频和视觉相关节点并优化配置
    - 启用audio_asr、audio_rkllm和audio_tts节点
    - 启用视觉管道容器(rk_camera+rk_inference+rk_streamer)
    - 修改audio_rkllm.launch.py中force_english参数为False
    - 简化uart/main.py中的JointState发布逻辑
    - 更新butter_robot.urdf中雷达和相机关节类型为fixed
    - 修改audio_tts.launch.py中的语音参数(音色ID和方言)
    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
    [butter_robot.urdf]
2026-01-20 docs: 添加黄油机器人系统开发文档
    添加完整的系统开发文档，包含系统架构、软件包清单、通信接口、坐标系与模型、启动运行说明、常见问题排查、系统特性与技术亮点、开发建议等内容。文档详细描述了ROS2系统的各个组件及其交互方式，为后续开发和维护提供参考。
2026-01-20 docs(skills): 添加ROS2 Python和CMake功能包创建技能文档
    添加两个技能文档，分别用于自动创建ROS2 Python和CMake功能包：
    1. ros2-create-pkg-python: 自动创建Python功能包并配置setup.py、package.xml等
    2. ros2-create-pkg-cmake: 自动创建CMake功能包并配置CMakeLists.txt、package.xml等
    包含完整的创建流程、配置说明和验证步骤，帮助开发者快速创建标准化的ROS2功能包
2026-01-20 refactor: 优化ROS2包依赖关系及性能改进
    - 移除未使用的依赖项如cv_bridge和opencv
    - 将build依赖调整为exec_depend以优化运行时
    - 预分配消息对象减少内存分配开销
    - 使用常量避免重复计算
    - 优化按钮处理逻辑减少列表创建
    - 添加编译器优化标志(O3和LTO)
    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
2026-01-20 refactor(ekf_odom): 更新轮式里程计话题名称从wheel_raw到wheel_odom refactor(slam): 调整TF发布频率和雷达最大距离以适应嵌入式平台 refactor(launch): 移除音频和视觉相关节点的启动配置 docs: 更新系统文档中的话题名称和参数说明
2026-01-21 feat: 初始化BMAD框架配置和核心工作流文件
    添加BMAD框架的配置文件、工作流模板和代理命令文件
    包括核心模块配置、BMM团队配置和各种工作流模板
    新增代理命令文件用于支持不同角色的工作流程
    [agent-manifest.csv, default-party.csv, files-manifest.csv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]
2026-02-08 chore: 清理文档图片并修复SLAM配置
    - 删除docs/source/_static/目录下的大量PNG和JPG图片文件
    - 新增package.json和bun.lock文件，添加bun依赖
    - 更新.gitignore，添加node_modules忽略项
    - 修复hy_slam配置，解决TF时间戳问题和雷达话题配置
    - 添加dynamic_tf_publisher脚本发布带时间戳的静态TF
    - 更新文档内容，优化产品介绍和开发指南
    - 调整规则文件的元数据配置
    - 重新启用视觉管道配置
    [mapper_params_online_async.yaml]
2026-02-08 docs: 更新文档配置并修正作者信息
    更新 Sphinx 配置以支持新的 Markdown 扩展，并调整作者和版权信息。添加 .readthedocs.yaml 和 requirements.txt 以启用 Read the Docs 自动构建。
2026-02-08 修改gitignore
    [agent-manifest.csv, default-party.csv, files-manifest.csv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]
2026-02-08 chore: 整理项目结构，忽略source大文件目录
    - .gitignore 添加 /source/ 忽略大文件（3.5G+）避免推送失败
    - 脚本文件从根目录迁移至 tools/ 目录
    - 移除 config/server/nfs_config.sh 及废弃的工具脚本
    - 更新文档和 readme
2026-02-08 feat: 添加Solidworks机器人模型文件
    [3000mAh���.SLDPRT, 3D_���ת�Ӱ�_2025-11-29.SLDPRT, 5000mAh���.SLDPRT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]
2026-02-08 docs: 重构项目文档结构并优化内容展示
    - 更新主标题为更具吸引力的产品宣传语
    - 将“开源地址”模块提前并细化分类，增加多个具体仓库链接
    - 重构“产品功能”章节，将详细描述改为表格形式，突出五大核心能力
    - 统一 readme.md 和文档源文件的内容，保持一致性
    - 优化章节标题格式，使用图标和简短描述提高可读性
2026-02-08 docs: 更新项目文档与链接并添加图片资源
    - 在项目文档开头添加“文档正在完善中”的提示
    - 更新“立创硬件开源”链接至新项目地址
    - 优化开发说明文档的格式、标点与措辞，提升可读性
    - 添加Solidworks设计图片资源
2026-02-08 docs: 修复文档中的链接格式和错别字
    修正 readme.md 和 product_introduction.md 中的链接格式问题，移除多余空格。
    将“开源源”更正为“开源”，统一表述。
2026-02-24 docs: 更新演示视频链接与描述
    将演示视频链接从私有网盘更新为B站公开链接，确保视频可公开访问。
    同时更新视频作者名称与视频标题以匹配B站内容。
2026-03-24 feat:Nav2 导航与黄油抓取任务功能包
    添加 hy_nav2 功能包，实现完整的自主导航与任务调度系统。该功能包包含：
    - butter_mission_node：状态机管理节点，协调搜索、导航、抓取和返回任务
    - Nav2 导航栈配置：适配黄油机器人的 AMCL、DWB 控制器和全局规划器参数
    - 启动文件：提供 nav2_bringup 和 butter_mission 启动配置
    - 测试文件：包含 PEP257、Flake8 和版权检查
    - 详细文档：在开发指南中新增 Nav2 部署章节，涵盖系统架构、任务流程和调试方法
    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
